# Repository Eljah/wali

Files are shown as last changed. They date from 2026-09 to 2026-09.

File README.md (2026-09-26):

# wali — робот-сборщик мусора на Java

Подготовленная для GitHub версия **UBOR-JAVA R02 / WPILib**, предназначенная для `Eljah/wali`.
Имя репозитория — `wali`; существующие Java-пакеты `com.ubor`, Maven-координаты и имена CAD-файлов сохранены.

> Это инженерный прототип, не готовый к автономной эксплуатации робот. WPILib включён в исходники R02, но сборка и выполнение WPILib в исходной среде не были подтверждены. Наличие этого пакета не означает, что репозиторий уже создан на GitHub.

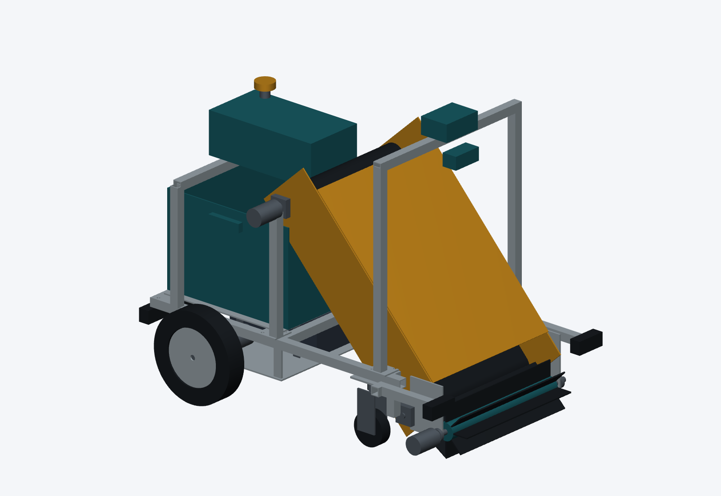
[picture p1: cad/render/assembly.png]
CAD-сборка робота


## Содержание

| Каталог | Материалы |
| --- | --- |
| `cad/` | Параметрические исходники, STEP, чертежи и спецификация механики. Нативных SolidWorks-файлов нет. |
| `electronics/` | Проект схем, перечень компонентов и соединений. |
| `software/` | Maven-проект: `robot-core`, `robot-app`, `robot-pi`, `robot-ml`, `robot-wpilib`. |
| `docs/` | Книга PDF/Markdown, глава о WPILib и инструкции. |
| `data/`, `models/` | Инструкции по данным и моделям; готовых обученных весов нет. |
| `verification/` | Сохранённые протоколы и ограничения проведённых проверок. |

## Сборка симулятора WPILib

Необходимы JDK 21, Maven 3.9+ и доступ к репозиториям зависимостей.

```bash
cd software
mvn -Pwpilib clean verify
```

Windows: `run-wpilib.cmd --desktop --nt`.
Linux: `./run-wpilib.sh --desktop --nt`.

Файл `software/dist/ubor-sim.jar` — проверенный **legacy-симулятор**, не готовая сборка WPILib.
Подробности: [README выпуска R02](README_RU.md) и [отчёт R02](verification/REPORT_R02_RU.md).
Автоматическая демонстрация использует известные сцене координаты и классы (`SIM_ORACLE_NOT_ML`), а не обученное машинное зрение.

## Документация

[Книга R02](docs/UBOR_JAVA_BOOK_R02.pdf) · [Глава WPILib](docs/25_WPILIB_R02.pdf) · [Сборка](docs/BUILD_RU.md).

## Создание репозитория

См. [PUBLISH_GITHUB_RU.md](PUBLISH_GITHUB_RU.md). Подготовлены `publish-github.ps1` и `publish-github.sh`.
По умолчанию они создают **приватный** `Eljah/wali`. Публикация требует входа в GitHub CLI на вашем компьютере.
Скрипты не заменяют существующий репозиторий и не используют force-push.
Исходные материалы R02 перенесены без изменения содержимого. Лицензия публикации автоматически не назначалась.

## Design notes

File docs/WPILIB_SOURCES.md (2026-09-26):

# Первичные источники WPILib

Версия backend зафиксирована: 2026.2.1. Просмотрено 23 сентября 2026.

- Physics Simulation: https://docs.wpilib.org/en/stable/docs/software/wpilib-tools/robot-simulation/physics-sim.html
- Drivetrain model: https://docs.wpilib.org/en/stable/docs/software/wpilib-tools/robot-simulation/drivesim-tutorial/drivetrain-model.html
- Simulated hardware: https://docs.wpilib.org/en/stable/docs/software/wpilib-tools/robot-simulation/drivesim-tutorial/simulation-instance.html
- DCMotorSim API: https://github.wpilib.org/allwpilib/docs/release/java/edu/wpi/first/wpilibj/simulation/DCMotorSim.html
- BatterySim API: https://github.wpilib.org/allwpilib/docs/release/java/edu/wpi/first/wpilibj/simulation/BatterySim.html
- EncoderSim API: https://github.wpilib.org/allwpilib/docs/release/java/edu/wpi/first/wpilibj/simulation/EncoderSim.html
- AnalogGyro API: https://github.wpilib.org/allwpilib/docs/release/java/edu/wpi/first/wpilibj/AnalogGyro.html
- Official release tag: https://github.com/wpilibsuite/allwpilib/releases/tag/v2026.2.1
- Java dependencies: https://github.com/wpilibsuite/allwpilib/blob/v2026.2.1/wpimath/build.gradle
- Native publications: https://github.com/wpilibsuite/allwpilib/blob/v2026.2.1/shared/jni/publish.gradle
- HAL native basename: https://github.com/wpilibsuite/allwpilib/blob/v2026.2.1/hal/build.gradle
- Runtime loading: https://github.com/wpilibsuite/allwpilib/blob/v2026.2.1/wpiutil/src/main/java/edu/wpi/first/util/RuntimeLoader.java

Публичная справка release может показывать версию 2026.2.2; tag для зависимости намеренно не плавающий. Наличие описания API не заменяет успешную сборку.

## Сторонние компоненты
WPILib — отдельная библиотека с лицензией BSD-3-Clause; EJML, Jackson и Quickbuf — сторонние зависимости со своими лицензиями. Бинарные зависимости в этом исходном архиве не распространяются. При создании готового дистрибутива необходимо сохранить уведомления об их лицензиях. Внутри WPILib используются штатные нативные библиотеки JNI; собственный код адаптера — Java.

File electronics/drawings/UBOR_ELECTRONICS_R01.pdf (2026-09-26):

# UBOR-JAVA R01 / Электроника

141 компонент · 100 именованных цепей · 8 дочерних схем KiCad. Вид PDF построен из канонического графа соединений, не экспортирован приложением KiCad.

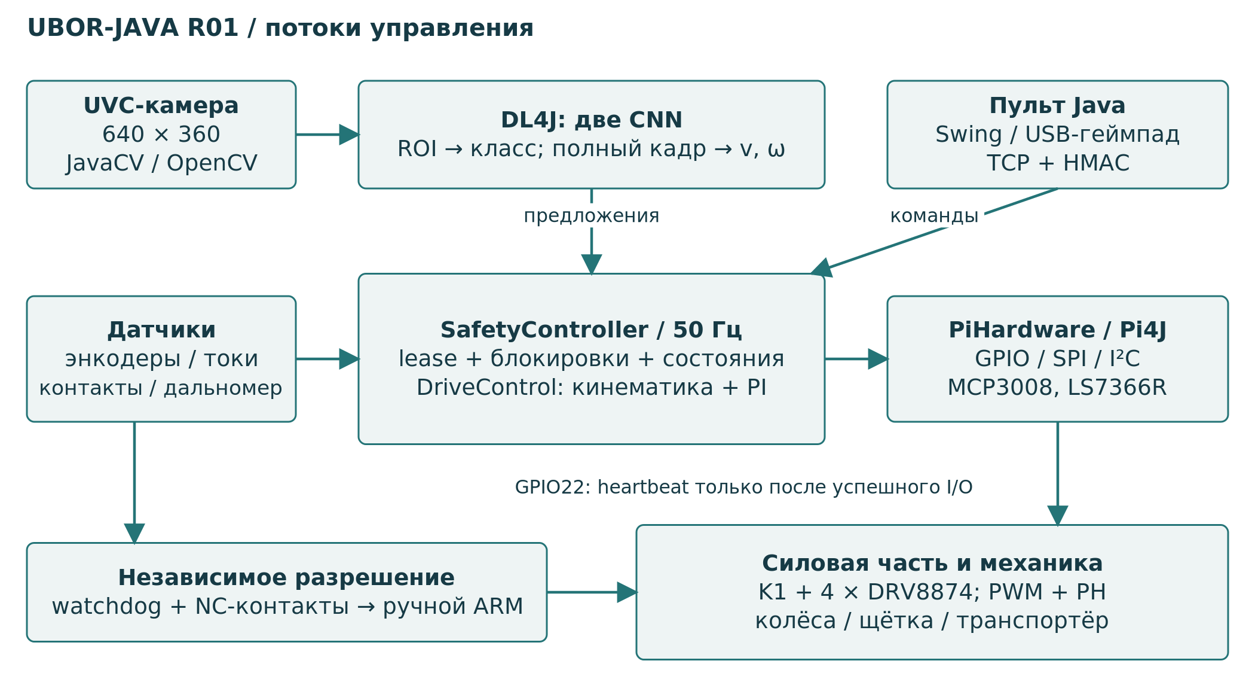
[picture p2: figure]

СТАТУС: структурная проверка выполнена. KiCad не запускался; ERC, PCB, DRC и SPICE не выполнены. Условные модульные разъёмы не являются готовыми footprint. Силовой выпуск запрещён до проверки рекуперации, тепла, предзаряда и выбранных компонентов.

Главный источник: electronics/connection_graph.json и wiring.csv. Корневой проект: electronics/kicad/UBOR_Electronics.kicad_pro. Отдельные NC-контакты состояния не соединять с цепями 24 В.

# Power / battery / precharge / motor contactor

R01 / canonical connection graph. KiCad ERC and PCB routing NOT performed.

BT1

8S LiFePO4 / BMS / 25.6V 10Ah

BAT_RAW | 1:PACK+ | 2:PACK- | GND

F1

15A DC fuse / near pack

BAT_RAW | 1:1 | 2:2 | BAT_FUSED

S0

Main DC disconnect

BAT_FUSED | 1:1 | 2:2 | BAT_SW

F2

3A logic branch

BAT_SW | 1:1 | 2:2 | BUCK_IN

PS1

Regulated 5.1V / 5A converter

BUCK_IN | 1:IN+
GND | 2:IN-
3:OUT+ | V5
4:OUT- | GND

## JUSB1

Pi5 USB-C power interface

V5 | 1:V5 | 2:GND | GND

K1

24V DC contactor + isolated feedback

BAT_SW | 1:MAIN_IN
VM_BUS | 2:MAIN_OUT
COIL_PLUS | 3:COIL+
4:COIL- | COIL_LOW
5:AUX_NO | K1_SENSE
6:AUX_COM | GND

S1B

E-STOP second NC pole

BAT_SW | 1:1 | 2:2 | COIL_PLUS

Q1

FQP30N06L / TO-220

K1_GATE | 1:G
COIL_LOW | 2:D
3:S | GND

D1

1N4007 coil diode

COIL_PLUS | 1:K | 2:A | COIL_LOW

RG1

100R gate

K1_GATE_DRIVE | 1:1 | 2:2 | K1_GATE

## RGS1

100k gate pulldown

K1_GATE | 1:1 | 2:2 | GND

## CBULK

10000uF / 50V low-ESR

VM_BUS | 1:1 | 2:2 | GND

## RBLEED

1k / 2W

VM_BUS | 1:1 | 2:2 | GND

## SPRE

Momentary PRECHARGE only

BAT_SW | 1:1 | 2:2 | PRE_R

## RPRE

22R / pulse >=5J

PRE_R | 1:1 | 2:2 | VM_BUS

## RVTOP

100k / 0.1%

BAT_SW | 1:1 | 2:2 | ADC_BAT

## RVBOT

10k / 0.1%

ADC_BAT | 1:1 | 2:2 | GND

CV

10nF

ADC_BAT | 1:1 | 2:2 | GND

# Hardware watchdog and edge-triggered manual rearm

## UWD

TPS3431 DRB

V3V3 | 1:VDD
CWD_SET | 2:CWD
V3V3 | 3:EN
GND | 4:GND
V3V3 | 5:SET1
6:WDI | HEARTBEAT
7:nWDO | WD_OK
8:ENOUT | WD_OK
9:PAD | GND

## RCWD

10k

V3V3 | 1:1 | 2:2 | CWD_SET

## RWDO

10k

V3V3 | 1:1 | 2:2 | WD_OK

## RWD_PD

100k

WD_OK | 1:1 | 2:2 | GND

S1A

E-STOP NC auxiliary

WD_OK | 1:1 | 2:2 | SAFE_1

S3A

Guard NC

SAFE_1 | 1:1 | 2:2 | SAFE_2

S4A

Bumper NC

SAFE_2 | 1:1 | 2:2 | SAFE_3

S5A

Cliff relay NC

SAFE_3 | 1:1 | 2:2 | CLEAR_N

## RCLR

100k

CLEAR_N | 1:1 | 2:2 | GND

## UFF

SN74LVC1G74 DCT/DCU

ARM_EDGE | 1:CLK
V3V3 | 2:D

3:nQ X

GND | 4:GND
5:Q | HW_ENABLE
6:nCLR | CLEAR_N
7:nPRE | V3V3
8:VCC | V3V3

## SARM

Physical ARM NO

V3V3 | 1:1 | 2:2 | ARM_BUTTON

## RARM

10k

ARM_BUTTON | 1:1 | 2:2 | ARM_RC

## RARM_PD

100k

ARM_RC | 1:1 | 2:2 | GND

## CARM

100nF

ARM_RC | 1:1 | 2:2 | GND

## USCH

SN74LVC1G17

1:NC X

ARM_RC | 2:A
GND | 3:GND
4:Y | ARM_EDGE
5:VCC | V3V3

## UAND

SN74LVC1G08

SOFT_ARM | 1:A
HW_ENABLE | 2:B
GND | 3:GND
4:Y | RUN_EN
5:VCC | V3V3

## UINV

SN74LVC1G04

1:NC X

RUN_EN | 2:A
GND | 3:GND
4:Y | PWM_OE
5:VCC | V3V3

## UGATE

SN74AHCT1G125

GND | 1:nOE
HW_ENABLE | 2:A
GND | 3:GND
4:Y | K1_GATE_DRIVE
5:VCC | V5

## RSA

10k

SOFT_ARM | 1:1 | 2:2 | GND

## RHB

10k

HEARTBEAT | 1:1 | 2:2 | GND

## RSLEEP

10k

RUN_EN | 1:1 | 2:2 | GND

## RHW

100k

HW_ENABLE | 1:1 | 2:2 | GND

## CWD

100nF at IC

V3V3 | 1:1 | 2:2 | GND

## CFF

100nF at IC

V3V3 | 1:1 | 2:2 | GND

## CSCH

100nF at IC

V3V3 | 1:1 | 2:2 | GND

## CAND

100nF at IC

V3V3 | 1:1 | 2:2 | GND

## CINV

100nF at IC

V3V3 | 1:1 | 2:2 | GND

## CGATE

100nF at IC

V5 | 1:1 | 2:2 | GND

# Raspberry Pi header and byte buses / 3.3V logic only

## JPI

Raspberry Pi5 40-pin header

V3V3 | 1:3V3
GND | 6:GND
I2C_SDA | 3:BCM2
I2C_SCL | 5:BCM3
SPI1_CS1 | 11:BCM17
SPI1_CS0 | 12:BCM18
SOFT_ARM | 13:BCM27
HEARTBEAT | 15:BCM22
ESTOP_SENSE | 16:BCM23
BUMPER_SENSE | 18:BCM24
SPI0_MOSI | 19:BCM10
SPI0_MISO | 21:BCM9
CLIFF_SENSE | 22:BCM25
23:BCM11 | SPI0_SCLK
24:BCM8 | SPI0_CS0
26:BCM7 | SPI0_CS1
29:BCM5 | GUARD_SENSE
31:BCM6 | FULL_SENSE
32:BCM12 | INTAKE_BEAM
33:BCM13 | DROP_BEAM
35:BCM19 | SPI1_MISO
36:BCM16 | DRV_FAULT_N
37:BCM26 | K1_SENSE
38:BCM20 | SPI1_MOSI
40:BCM21 | SPI1_SCLK

## UADC

MCP3008 / DIP-16

ADC_BAT | 1:CH0
CUR0 | 2:CH1
CUR1 | 3:CH2
CUR2 | 4:CH3
CUR3 | 5:CH4
RANGE_OUT | 6:CH5
GND | 7:CH6
GND | 8:CH7
9:DGND | GND
10:nCS | SPI0_CS0
11:DIN | SPI0_MOSI
12:DOUT | SPI0_MISO
13:CLK | SPI0_SCLK
14:AGND | GND
15:VREF | V3V3
16:VDD | V3V3

## UDIR

MCP23S17 / DIP-28

V3V3 | 9:VDD
GND | 10:VSS
SPI0_CS1 | 11:nCS
SPI0_SCLK | 12:SCK
SPI0_MOSI | 13:SI
SPI0_MISO | 14:SO
GND | 15:A0
16:A1 | GND
17:A2 | GND
18:nRESET | DIR_RST
21:GPA0 | DIR0
22:GPA1 | DIR1
23:GPA2 | DIR2
24:GPA3 | DIR3

## RDIR

10k

V3V3 | 1:1 | 2:2 | DIR_RST

## UPWM

PCA9685 / TSSOP28

GND | 1:A0
GND | 2:A1
GND | 3:A2
GND | 4:A3
GND | 5:A4
PWM0 | 6:LED0
PWM1 | 7:LED1
PWM2 | 8:LED2
9:LED3 | PWM3
14:VSS | GND
23:nOE | PWM_OE
24:A5 | GND
25:SCL | I2C_SCL
26:SDA | I2C_SDA
27:EXTCLK | GND
28:VDD | V3V3

## ROE

10k

V3V3 | 1:1 | 2:2 | PWM_OE

## UENC0

LS7366R / DIP14

1:fCKO X

ENC_CLK | 2:fCKi
GND | 3:VSS
SPI1_CS0 | 4:nSS
SPI1_SCLK | 5:SCK
SPI1_MISO | 6:MISO
SPI1_MOSI | 7:MOSI
8:nLFLAG | X
9:nDFLAG | X
10:nINDEX | V3V3
11:B | ENC0B
12:A | ENC0A
13:CNT_EN | V3V3
14:VDD | V3V3

## JENC0

Encoder / 3.3V quadrature

V3V3 | 1:3V3
ENC0A | 2:A
3:B | ENC0B
4:GND | GND

## UENC1

LS7366R / DIP14

1:fCKO X

ENC_CLK | 2:fCKi
GND | 3:VSS
SPI1_CS1 | 4:nSS
SPI1_SCLK | 5:SCK
SPI1_MISO | 6:MISO
SPI1_MOSI | 7:MOSI
8:nLFLAG | X
9:nDFLAG | X
10:nINDEX | V3V3
11:B | ENC1B
12:A | ENC1A
13:CNT_EN | V3V3
14:VDD | V3V3

## JENC1

Encoder / 3.3V quadrature

V3V3 | 1:3V3
ENC1A | 2:A
3:B | ENC1B
4:GND | GND

X1

1MHz CMOS oscillator / 3.3V

V3V3 | 1:OE
GND | 2:GND
3:OUT | ENC_CLK
4:VDD | V3V3

## CADC

100nF at IC

V3V3 | 1:1 | 2:2 | GND

## CDIR

100nF at IC

V3V3 | 1:1 | 2:2 | GND

## CPWM

100nF at IC

V3V3 | 1:1 | 2:2 | GND

## CENC0

100nF at IC

V3V3 | 1:1 | 2:2 | GND

## CENC1

100nF at IC

V3V3 | 1:1 | 2:2 | GND

CX

100nF at IC

V3V3 | 1:1 | 2:2 | GND

# Dry-contact safety sensing / beam inputs / range output

## SES

NC healthy; dedicated isolated auxiliary pole

ESTOP_SENSE | 1:1 | 2:2 | GND

## RSES

10k external pullup

V3V3 | 1:1 | 2:2 | ESTOP_SENSE

## SBU

NC healthy; separate contact from CLEAR chain

BUMPER_SENSE | 1:1 | 2:2 | GND

## RSBU

10k external pullup

V3V3 | 1:1 | 2:2 | BUMPER_SENSE

## SCL

NC healthy from validated cliff detector

CLIFF_SENSE | 1:1 | 2:2 | GND

## RSCL

10k external pullup

V3V3 | 1:1 | 2:2 | CLIFF_SENSE

## SGU

NC healthy

GUARD_SENSE | 1:1 | 2:2 | GND

## RSGU

10k external pullup

V3V3 | 1:1 | 2:2 | GUARD_SENSE

## SFU

NC healthy; opens when hopper full

FULL_SENSE | 1:1 | 2:2 | GND

## RSFU

10k external pullup

V3V3 | 1:1 | 2:2 | FULL_SENSE

JB0

Beam receiver / open collector

V5 | 1:V5
INTAKE_BEAM | 2:OC_3V3
3:GND | GND

RB0

10k

V3V3 | 1:1 | 2:2 | INTAKE_BEAM

JB1

Beam receiver / open collector

V5 | 1:V5
DROP_BEAM | 2:OC_3V3
3:GND | GND

RB1

10k

V3V3 | 1:1 | 2:2 | DROP_BEAM

RF

10k external pullup

V3V3 | 1:1 | 2:2 | DRV_FAULT_N

RK

10k external pullup

V3V3 | 1:1 | 2:2 | K1_SENSE

## JRANGE

Calibrated analog obstacle sensor

V5 | 1:V5
RANGE_OUT | 2:OUT_0_3V3
3:GND | GND

# DRV8874 channel 0: left

FM0

4A DC

VM_BUS | 1:1 | 2:2 | M0_VM

UM0

DRV8874 HTSSOP16-PAD

PWM0 | 1:EN
DIR0 | 2:PH
RUN_EN | 3:nSLEEP
DRV_FAULT_N | 4:nFAULT
M0_VREF | 5:VREF
M0_IP | 6:IPROPI
GND | 7:IMODE
M0_OUT1 | 8:OUT1
GND | 9:PGND
10:OUT2 | M0_OUT2
11:VM | M0_VM
12:VCP | M0_VCP
13:CPH | M0_CPH
14:CPL | M0_CPL
15:GND | GND
16:PMODE | GND
17:PAD | GND

M0

24V brushed gearmotor

M0_OUT1 | 1:+ / forward | 2:- / reverse | M0_OUT2

## CCP0

22nF / 50V

M0_CPH | 1:1 | 2:2 | M0_CPL

## CVCP0

100nF /16V

M0_VCP | 1:1 | 2:2 | M0_VM

## CVM0

100nF /50V

M0_VM | 1:1 | 2:2 | GND

CB0

470uF /50V

M0_VM | 1:1 | 2:2 | GND

## RIP0

1.5k /1%

M0_IP | 1:1 | 2:2 | GND

## RFLT0

10k

M0_IP | 1:1 | 2:2 | CUR0

## CFLT0

100nF

CUR0 | 1:1 | 2:2 | GND

## RVT0

6.19k /1%

V3V3 | 1:1 | 2:2 | M0_VREF

## RVB0

10k /1%

M0_VREF | 1:1 | 2:2 | GND

## REN0

47k

PWM0 | 1:1 | 2:2 | GND

## RPH0

47k

DIR0 | 1:1 | 2:2 | GND

CM0

10nF /50V motor suppression

M0_OUT1 | 1:1 | 2:2 | M0_OUT2

# DRV8874 channel 1: right

FM1

4A DC

VM_BUS | 1:1 | 2:2 | M1_VM

UM1

DRV8874 HTSSOP16-PAD

PWM1 | 1:EN
DIR1 | 2:PH
RUN_EN | 3:nSLEEP
DRV_FAULT_N | 4:nFAULT
M1_VREF | 5:VREF
M1_IP | 6:IPROPI
GND | 7:IMODE
M1_OUT1 | 8:OUT1
GND | 9:PGND
10:OUT2 | M1_OUT2
11:VM | M1_VM
12:VCP | M1_VCP
13:CPH | M1_CPH
14:CPL | M1_CPL
15:GND | GND
16:PMODE | GND
17:PAD | GND

M1

24V brushed gearmotor

M1_OUT1 | 1:+ / forward | 2:- / reverse | M1_OUT2

## CCP1

22nF / 50V

M1_CPH | 1:1 | 2:2 | M1_CPL

## CVCP1

100nF /16V

M1_VCP | 1:1 | 2:2 | M1_VM

## CVM1

100nF /50V

M1_VM | 1:1 | 2:2 | GND

CB1

470uF /50V

M1_VM | 1:1 | 2:2 | GND

## RIP1

1.5k /1%

M1_IP | 1:1 | 2:2 | GND

## RFLT1

10k

M1_IP | 1:1 | 2:2 | CUR1

## CFLT1

100nF

CUR1 | 1:1 | 2:2 | GND

## RVT1

6.19k /1%

V3V3 | 1:1 | 2:2 | M1_VREF

## RVB1

10k /1%

M1_VREF | 1:1 | 2:2 | GND

## REN1

47k

PWM1 | 1:1 | 2:2 | GND

## RPH1

47k

DIR1 | 1:1 | 2:2 | GND

CM1

10nF /50V motor suppression

M1_OUT1 | 1:1 | 2:2 | M1_OUT2

# DRV8874 channel 2: brush

FM2

3A DC

VM_BUS | 1:1 | 2:2 | M2_VM

UM2

DRV8874 HTSSOP16-PAD

PWM2 | 1:EN
DIR2 | 2:PH
RUN_EN | 3:nSLEEP
DRV_FAULT_N | 4:nFAULT
M2_VREF | 5:VREF
M2_IP | 6:IPROPI
GND | 7:IMODE
M2_OUT1 | 8:OUT1
GND | 9:PGND
10:OUT2 | M2_OUT2
11:VM | M2_VM
12:VCP | M2_VCP
13:CPH | M2_CPH
14:CPL | M2_CPL
15:GND | GND
16:PMODE | GND
17:PAD | GND

M2

24V brushed gearmotor

M2_OUT1 | 1:+ / forward | 2:- / reverse | M2_OUT2

## CCP2

22nF / 50V

M2_CPH | 1:1 | 2:2 | M2_CPL

## CVCP2

100nF /16V

M2_VCP | 1:1 | 2:2 | M2_VM

## CVM2

100nF /50V

M2_VM | 1:1 | 2:2 | GND

CB2

470uF /50V

M2_VM | 1:1 | 2:2 | GND

## RIP2

1.5k /1%

M2_IP | 1:1 | 2:2 | GND

## RFLT2

10k

M2_IP | 1:1 | 2:2 | CUR2

## CFLT2

100nF

CUR2 | 1:1 | 2:2 | GND

## RVT2

14.3k /1%

V3V3 | 1:1 | 2:2 | M2_VREF

## RVB2

10k /1%

M2_VREF | 1:1 | 2:2 | GND

## REN2

47k

PWM2 | 1:1 | 2:2 | GND

## RPH2

47k

DIR2 | 1:1 | 2:2 | GND

CM2

10nF /50V motor suppression

M2_OUT1 | 1:1 | 2:2 | M2_OUT2

# DRV8874 channel 3: belt

FM3

3A DC

VM_BUS | 1:1 | 2:2 | M3_VM

UM3

DRV8874 HTSSOP16-PAD

PWM3 | 1:EN
DIR3 | 2:PH
RUN_EN | 3:nSLEEP
DRV_FAULT_N | 4:nFAULT
M3_VREF | 5:VREF
M3_IP | 6:IPROPI
GND | 7:IMODE
M3_OUT1 | 8:OUT1
GND | 9:PGND
10:OUT2 | M3_OUT2
11:VM | M3_VM
12:VCP | M3_VCP
13:CPH | M3_CPH
14:CPL | M3_CPL
15:GND | GND
16:PMODE | GND
17:PAD | GND

M3

24V brushed gearmotor

M3_OUT1 | 1:+ / forward | 2:- / reverse | M3_OUT2

## CCP3

22nF / 50V

M3_CPH | 1:1 | 2:2 | M3_CPL

## CVCP3

100nF /16V

M3_VCP | 1:1 | 2:2 | M3_VM

## CVM3

100nF /50V

M3_VM | 1:1 | 2:2 | GND

CB3

470uF /50V

M3_VM | 1:1 | 2:2 | GND

## RIP3

1.5k /1%

M3_IP | 1:1 | 2:2 | GND

## RFLT3

10k

M3_IP | 1:1 | 2:2 | CUR3

## CFLT3

100nF

CUR3 | 1:1 | 2:2 | GND

## RVT3

14.3k /1%

V3V3 | 1:1 | 2:2 | M3_VREF

## RVB3

10k /1%

M3_VREF | 1:1 | 2:2 | GND

## REN3

47k

PWM3 | 1:1 | 2:2 | GND

## RPH3

47k

DIR3 | 1:1 | 2:2 | GND

CM3

10nF /50V motor suppression

M3_OUT1 | 1:1 | 2:2 | M3_OUT2

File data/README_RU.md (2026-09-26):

# Данные обучения

Реального датасета в R01 нет. PNG, созданные симулятором, — синтетические диагностические кадры, а не обучающая выборка с заявленной точностью.

На этапе объездки Java DatasetRecorder записывает кадры и manifest в явно заданный выходной каталог. Метки предметов задаёт человек. В manifest сохраняются разрешённые контроллером, а не просто запрошенные, линейная и угловая скорости. Примеры файлов разбиения по целым сессиям и bounding boxes находятся в `software/config`.

Сначала собрать независимые поездки, затем разнести целые session_id между train/validation/test, проверить метки и подготовить отдельные ROI для классификатора. Модель движения обучается на полном кадре. Команды подготовки, обучения и проверки приведены в главах 16–19 книги. Соседние кадры одной поездки нельзя случайно перемешивать между обучением и тестом.

Обученных моделей в архиве нет. Их контрольные суммы, статус допуска и согласованные параметры камеры должны оформляться после целевых испытаний.

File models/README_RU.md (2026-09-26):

# Модели намеренно не подменены заглушками

В комплекте нет обученных весов, полевых фотографий и придуманной точности.
Исходники двух CNN, обучения и проверки — `software/robot-ml`.

Аппаратный режим ожидает `classifier.zip` и `policy.zip` с соответствующими
`*.zip.properties`, создаваемыми `com.ubor.ml.Trainer`.
Преобразование RGB64 NCHW, порядок классов, SHA-256, `kind` и
`approved.for.hardware` проверяются загрузчиком. Trainer записывает
`approved.for.hardware=false`; перевод в true — ручной выпуск после независимой
проверки метрик, локализации, времени получения кадра и работы на стенде.

`--desktop` и `--demo` не используют нейросеть. Их распознавание — oracle из
состояния мира. Для первичного датасета есть `--hardware-teleop` (только камера).
Никогда не обучайте реальную модель на oracle-кадрах с обещанием полевой точности.

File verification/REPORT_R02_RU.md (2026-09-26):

# Проверка UBOR R02 / WPILib

Дата выпуска: 23 сентября 2026. Среда: Linux x86-64, OpenJDK 21.0.11.

| Объект | Результат | Доказательство |
|---|---|---|
| Компиляция robot-core + robot-app | PASS | offline-build.log; software/dist/ubor-sim.jar |
| Прежние проверки ядра и интеграции | PASS, 50 assertions | r02-core/ |
| Граница сменной физики | PASS, 20 assertions, тестовая модель | r02-boundary/ |
| Загрузка/валидация параметров | PASS, 9 assertions, без WPILib | r02-parameters/ |
| Реальный TCP/HMAC loopback | PASS, 40 обменов, останов после отключения | network-legacy-r02.txt |
| Синтаксис Java | PASS, 37 файлов, только parse | java-parse.txt |
| Компиляция модуля robot-wpilib | NOT RUN | wpilib-build-attempt.txt; Maven отсутствует |
| Загрузка WPILib | BLOCKED | dependency-download-attempt.txt; DNS/соединение недоступны |
| Native HAL / WPILib runtime | NOT RUN | wpilib-launch-attempt.txt |
| 25 проверок WpiVerification | Подготовлены; НЕ выполнены | software/robot-wpilib/src/main/java/com/ubor/wpilib/WpiVerification.java |
| Windows / macOS | НЕ выполнено | предусмотрены скрипт и профили, без подтверждённого запуска |
| Raspberry Pi / Pi4J / DL4J / аппаратная часть | НЕ выполнено в R02 | исходные ограничения R01 сохраняются |

**Нельзя считать 50+20+9 проверок доказательством работающей WPILib.** В тестах границы используется класс Probe с именем `TEST_DOUBLE_NOT_WPILIB`. Он не подменяет классы edu.wpi.first.* и не входит в WPILib backend.

Выполненная проверка синтаксиса использует JavacTask.parse(): импорты и сигнатуры внешних библиотек ею НЕ проверяются. Никакие суррогатные классы WPILib для имитации успешной компиляции не создавались.

Для полной проверки: из `software` выполнить `mvn -Pwpilib clean verify`. Отчёт нового запуска должен появиться в `robot-wpilib/target/wpilib-report/result.json`. Только статус PASS этого нового запуска подтверждает выполнение подготовленных WPILib-сценариев. В начале проверки отчёт заменяется на RUNNING_NOT_YET_PASSED, чтобы не оставлять ложный старый PASS при аварийном завершении.

Механика, электронные схемы и ML не стали автоматически верифицированными после добавления симулятора. Модель движения требует калибровки по физическому роботу; моменты инерции и параметры двигателей пока задают гипотезу.

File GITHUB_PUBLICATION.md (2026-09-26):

# GitHub publication

The original wali/UBOR-JAVA R02 package was imported as ordinary files. All 316 source files were checked byte-for-byte against the exact original archive, including the 307 entries of its original manifest.

See verification/github-import.json and verification/github-source-manifest.json. The pre-publication reports remain unchanged historical records. This import does not establish that WPILib, DL4J or physical hardware tests passed.

The pre-existing lowercase readme.md was preserved as docs/ORIGINAL_REPOSITORY_README.md to avoid a case-insensitive filesystem collision. No force-push was used.

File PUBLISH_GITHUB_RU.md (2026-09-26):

# Публикация `Eljah/wali`

## Текущее состояние

Этот пакет подготовлен локально. Репозиторий **не создан**, файлы в GitHub **не отправлены**.
GitHub-подключение в чате подтвердило аккаунт Eljah, но не предоставило операций создания/записи;
в рабочей среде не было авторизованного CLI. Запрос `Eljah/wali` вернул 404:
это не доказывает отсутствие репозитория, поскольку он мог быть недоступен подключению.

## Перед запуском

Установите Git и GitHub CLI (`gh`). На Windows доступны команды:

```powershell
winget install --id Git.Git --exact
winget install --id GitHub.cli --exact
```

Откройте новый терминал после установки. Распакуйте ZIP и перейдите в каталог `wali`.
Не добавляйте в него реальные ключи, записи личных данных и пароли перед публикацией.

Выполните вход через браузер именно в аккаунт **Eljah**:

```text
gh auth login --hostname github.com --git-protocol https --web
```

Разрешите настройку аутентификации Git, когда CLI спросит об этом.
Токены и пароль в чат передавать не нужно.

## Windows / PowerShell

```powershell
powershell -NoProfile -ExecutionPolicy Bypass -File .\publish-github.ps1
```

`-ExecutionPolicy Bypass` действует только для этого запуска PowerShell и не меняет постоянную политику.
Сначала ознакомьтесь с текстом скрипта. По умолчанию репозиторий будет **private**.
Для осознанной публичной публикации добавьте `-Visibility public`.

## Linux / macOS / Git Bash

```bash
bash publish-github.sh
```

Для публичной публикации: `bash publish-github.sh public`.

## Что делает скрипт

Проверяет наличие файлов и программ, получает аккаунт через `gh api user` и требует `Eljah`.
При наличии локального `.git` останавливается, не меняя существующий репозиторий.
Создаёт локальную ветку `main`, задаёт имя и noreply-email автора **только в локальной Git-конфигурации**,
добавляет материалы и создаёт первый коммит. Затем вызывает:

```text
gh repo create Eljah/wali --private --source=. --remote=origin --push
```

В конце сравнивает SHA локального коммита и удалённой `main`.
Скрипт не удаляет репозитории, не меняет видимость существующего репозитория и не делает force-push.
Приватность существующего репозитория не изменяется.

## При сбое

При ошибке скрипт завершается. Локальная `.git` может уже существовать; удалённый репозиторий мог быть
создан до ошибки отправки. **Не удаляйте его и не используйте `--force`.** Проверьте:

```text
git status
git remote -v
gh repo view Eljah/wali --json nameWithOwner,url,isPrivate
```

Если подтверждено, что это созданный этим запуском пустой репозиторий, а `origin` указывает именно на него,
после устранения проблемы авторизации достаточно `git push -u origin main`.
Если репозиторий существовал раньше, сопоставьте его содержимое с проектом отдельно; скрипт его не заменяет.

## Проверка пакета

308 исходных файлов R02 сохранены байт-в-байт; добавлены только файлы оформления и публикации.
Проверки упаковки не заменяют запуск WPILib или испытания электроники.
Публикация через реальный GitHub API здесь не выполнялась.

## Официальная документация CLI

- https://cli.github.com/manual/gh_repo_create
- https://cli.github.com/manual/gh_auth_login
- https://cli.github.com/manual/gh_auth_setup-git

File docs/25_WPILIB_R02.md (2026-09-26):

# Глава 25. Интеграция WPILib — UBOR R02

Дата: 23 сентября 2026. Исходный код; WPILib-сборка не верифицирована.

## 25. WPILib в проекте UBOR

R02 заменяет способ расчёта движения, а не архитектуру управления. Пульт, сетевой протокол, SafetyController и DriveControl остаются теми же. Между сценой Simulator и физической моделью появился интерфейс SimDynamics; его реализация WpilibDynamics вызывает классы WPILib 2026.2.1.

**Статус: исходный код интеграции подготовлен. Сборка и выполнение WPILib здесь НЕ проверены: Maven отсутствует, загрузка бинарных зависимостей недоступна. Работоспособность готового WPILib-дистрибутива этим выпуском не заявляется.**

### Как проходит один цикл

```text
TCP/HMAC -> RobotService
  -> SafetyController -> DriveControl -> Actuation
  -> Simulator -> WpilibDynamics
  -> физическое состояние и HAL-датчики
  -> Sensors -> следующий цикл контроллера
```

Simulator больше не вычисляет координаты в WPILib-пути. Он получает готовую позу, скорости колёс, путь, скорости механизмов, токи и напряжение. Старый способ расчёта оставлен для регрессионной проверки и всегда называется LEGACY_FIRST_ORDER.

### Что осталось от R01

Механика STEP/CAD и электрические схемы не менялись. Аппаратный адаптер Pi4J и код DL4J сохранены. Включение профиля wpilib не собирает профиль full и не требует загружать библиотеки обучения. В собственной программе нет кода C/C++; штатные нативные библиотеки WPILib используются через JNI.

Вариант запуска называется явно. run-simulator теперь вызывает WPILib; run-legacy-simulator вызывает старый JAR. Если WPILib не собран или не загружается JNI, запуск завершается ошибкой. Автоматического перехода к старой физике нет.

## 25.1. Приводы и батарея

Для дифференциального шасси применяется DifferentialDrivetrainSim. Щётка и приводной ролик транспортёра представлены двумя DCMotorSim. Напряжение на моторе получается из PWM-доли и напряжения шины, а не из прямого назначения скорости колесу.

| Параметр | Значение / происхождение |
|---|---|
| Масса; колея; радиус | 30 кг; 0,5 м; 0,1 м — исходные условия R01 |
| Момент инерции по курсу | 2,4 кг·м² — оценка, не измерение CAD-массовой модели |
| Редукции: колёса / щётка / лента | 112,5 / 25 / 38,8 — допущения |
| Моторы | Собственные наборы DCMotor на 24 В; не NEO/CIM из примера FRC |
| Батарея | 25,6 В; 0,09 Ом; электроника 1 А — допущения |
| Радиус ролика | 0,025 м; скорость ленты = угловая скорость × радиус |

Конфигурация находится в config/wpilib-sim.properties. Параметры двигателя относятся к валу ДО редуктора; смешение паспортных характеристик редукторного выхода с коэффициентом редукции удвоит преобразование. Ширина колеи и радиус дополнительно сверяются с константами DriveControl.

### Просадка питания

```text
I_source = I_logic + sum(max(0, duty * I_winding))
V_loaded = BatterySim.calculateLoadedBatteryVoltage(
    V_open, R_internal, I_source)
```

Ток, который видит датчик мотора, — модуль тока обмотки. Для батареи используется оценка среднего входного тока PWM. Установлено напряжение моделируемой шины 25,6 В: стандартные 12 В из FRC-примеров не подставляются автоматически. Химия, заряд батареи, температура, токовые ограничения драйвера и рекуперативное перенапряжение здесь не моделируются.

## 25.2. HAL, время и отключение

WpiSensors записывает результат модели в EncoderSim, AnalogInputSim, DIOSim и RoboRioSim, затем считывает его через обычные объекты WPILib. Именно эти показания энкодеров и токов поступают в общий контроллер. Это проверяет программную обратную связь, но не исполняет SPI-протокол LS7366R/MCP3008 и не эмулирует Raspberry Pi.

| Виртуальные каналы | Назначение |
|---|---|
| DIO 0–3 | Два энкодера; метры и импульсы согласованы с DriveControl |
| AI 0 | AnalogGyroSim: диагностический угол, не реальный IMU в схеме |
| AI 1 / AI 2–5 | Дальность 1 В/м / токи 0,5 В/А; насыщение 0–5 В |
| DIO 4–12 | NC-защиты, заполнение, разрешение, ошибка драйвера, два луча |
| RoboRioSim VIn | Симулируемая шина питания, а не питание физического roboRIO |

Ось курса в физике положительна против часовой стрелки; AnalogGyro.getAngle использует противоположный знак. Адаптер учитывает это. Гироскоп используется для диагностики и отдельной проверки, а существующий контур DriveControl регулирует скорости по энкодерам.

### Частоты и защёлки

Управляющий цикл работает с периодом 20 мс. Физика разбивается на подшаги до 5 мс, независимо от интерфейса пульта. Истечение 200-мс watchdog размыкает виртуальное разрешение; очистка аварийного признака не включает питание. Требуется новое действие Physical ARM. Пауза модели свыше 5 с отклоняется явно, а не маскируется потерей времени.

**Обесточить моторы — не то же самое, что мгновенно остановить колёса. Нулевое входное напряжение в DC-модели соответствует электрическому торможению. Для разомкнутой цепи в R02 введена отдельная приближённая модель выбега с пассивным сопротивлением. Её коэффициент НЕ откалиброван; безопасный тормозной путь не подтверждён.**

## 25.3. Сборка и работа с пультом

Требования: JDK 21, Maven 3.9+ и доступ к Maven Central/FRCMaven. В pom зафиксирована WPILib 2026.2.1. Схема сборки использует Java JAR и платформенные архивы *-cpp с JNI/shared-библиотеками. Maven распаковывает библиотеки в target/native; скрипты задают java.library.path и путь поиска зависимых DLL/SO.

```text
cd software
mvn -Pwpilib clean verify
```

verify запускает реальные проверки WPILib отдельной JVM. Файлы Java из robot-pi/robot-ml не включаются, пока не выбран профиль full. Для Windows предусмотрен windowsx86-64, для Linux — linuxx86-64, для macOS — osxuniversal; эти платформенные сборки в данной среде не проверены. Linux ARM не является целевой конфигурацией этого настольного запуска.

### Windows

```text
run-wpilib.cmd --about
run-wpilib.cmd --desktop --nt
run-wpilib.cmd --demo ..\verification\my-demo 90
```

### Linux

```text
./run-wpilib.sh --about
./run-wpilib.sh --desktop --nt
./run-wpilib.sh --demo ../verification/my-demo 90
```

В пульте сначала нажать Physical ARM (SIM), затем Arm / Disarm и удерживать SPACE. Движение — стрелки/WASD; C — ручной подбор с человеческой меткой. Для записи добавить --record каталог. Это синтетические кадры симулятора, а не фотографии полигона.

Опция --nt публикует Field2d и телеметрию на 127.0.0.1:5810 для Glass. Команды управления по NetworkTables не принимаются. В headless-режиме --server доступны консольные команды arm, estop, restore, jam; сетевой сервер также по умолчанию слушает только loopback.

## 25.4. Что проверено, а что нет

| Проверка в среде подготовки | Результат |
|---|---|
| Ядро + старый симулятор | 50 проверок — PASS |
| Интерфейс сменной физики | 20 проверок с TEST_DOUBLE_NOT_WPILIB — PASS |
| Конфигурация физических параметров | 9 проверок без WPILib — PASS |
| TCP/HMAC на старой модели | 40 обменов и останов после разрыва — PASS |
| Синтаксис Java | 37 файлов, только parse — PASS |
| Компиляция / исполнение WPILib | НЕ ВЫПОЛНЕНО |
| WpiVerification | 25 проверок подготовлены, НЕ выполнены |

Двадцать проверок интерфейса подтверждают, что сцена берёт координаты, скорости и токи из подключённого backend; не пересчитывает их повторно; передаёт останов и заклинивание; закрывает ресурсы ровно один раз. Тестовая модель намеренно имеет отличное от WPILib имя и не подменяет классы edu.wpi.first.*.

Реальная suite WpiVerification должна проверить движение прямо и назад, поворот, знак гироскопа, энкодеры HAL, 25-вольтовую шину, выбег после отключения, вращение щётки/ролика, заклинивание и токи, watchdog, аварийные защёлки, полный сбор трёх предметов и TCP-отключение.

### Где смотреть результат

```text
robot-wpilib/target/wpilib-report/result.json
robot-wpilib/target/wpilib-report/wpilib-origin.txt
robot-wpilib/target/wpilib-report/oracle-demo/
verification/REPORT_R02_RU.md
```

В начале запуска статус заменяется на RUNNING_NOT_YET_PASSED. При исключении записывается FAIL; только завершение всей suite формирует PASS. Источник JAR фиксируется отдельно. Протоколы r01_archive и r02-core не являются свидетельством выполнения WPILib. Проверка parse не проверяет типы и внешние сигнатуры.

## 25.5. Границы модели и следующий стенд

Зрение в демонстрации называется SIM_ORACLE_NOT_ML: класс и координаты предмета известны сцене. WPILib не превращает такую демонстрацию в проверку DL4J. Качество детекции, обучение рулению, ложные срабатывания на тени и неизвестных предметах требуют отдельного набора данных и испытаний.

Сбор мусора остаётся геометрическим автоматом: предмет входит в зону подборщика, переходит на ленту и затем в бункер. Скорость продвижения теперь зависит от скорости ролика DCMotorSim. Если механизмы стоят, одной положительной команды недостаточно. Контакт не моделирует пластичность бутылки, изгиб бумаги, наматывание пакета и силы щетины.

Из сцены убрана ошибка R01: проверка collectible() в самой механике запрещала подбор опасного предмета даже при неверном управлении. Теперь материальный объект не имеет такой защиты, и запрет должен обеспечивать контроллер. Отдельная проверка интерфейса подтверждает возможность физического захвата объекта HAZARD при прямой неправильной команде.

### Калибровка после появления прототипа

Сначала определить параметры купленных двигателей и редукторов, действительные импульсы энкодеров, массы и моменты инерции. На вывешенных колёсах снять скорость и ток как функции PWM/напряжения; на полу измерить разгон, поворот и свободный выбег с разной загрузкой. Сравнивать временные ряды энкодеров и токов, а не только конечную точку маршрута.

Для этапа сборщика отдельно измерить разгон щётки и ленты, ток при контакте с эталонными предметами и последствия наматывания. Сначала завершить независимую аварийную цепь и физические испытания защиты. Программная симуляция не обосновывает безопасное использование рядом с людьми.

### Первичные источники

WPILib: Physics Simulation, Drivetrain Simulation Tutorial, Device Simulation, API DCMotorSim/BatterySim. Исходные сигнатуры и состав зависимостей сверены с репозиторием wpilibsuite/allwpilib, тег v2026.2.1. Полные адреса приведены в docs/WPILIB_SOURCES.md. Новая глава дополняет R01 и не снимает его инженерных ограничений.

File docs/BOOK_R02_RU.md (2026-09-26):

# UBOR R02: исходная книга R01 + дополнение WPILib

Статус WPILib: код интеграции; сборка и запуск не проверены.

# Предисловие. От идеи к проверяемой машине

Робот, который узнаёт бутылку на фотографии, и робот, который доставляет эту бутылку в бункер, — разные устройства. Между ними лежат геометрия входного окна, сцепление колёс, ток двигателя, задержка камеры, состояние ленты и решение оператора. Эта книга описывает один связанный проект, а не коллекцию независимых примеров. Его имя — UBOR-JAVA R01.

Проект создан для проверки идеи на закрытом полигоне. Он включает настоящую твердотельную CAD-модель, схему соединений электроники, исходный Java-проект, запускаемый симулятор и код обучения. При этом физический робот ещё не построен, аппаратные модули не прошли проверку на Raspberry Pi, а обученных весов в комплекте нет. Эти границы важны: хороший инженерный прототип начинается с возможности точно сказать, что уже проверено, а что пока является гипотезой.

Слово «прошивка» здесь используется в бытовом смысле бортового программного обеспечения. Самостоятельной платы с STM32 и программой на C в R01 нет. На Raspberry Pi работает Java-процесс, который читает датчики, формирует команды приводам, принимает пульт и вызывает нейросети. Таймер PWM, аппаратные счётчики энкодеров и сторожевой таймер выполняются покупными микросхемами без нашей микропрограммы. Linux, JVM и численные библиотеки, разумеется, не переписываются на Java.

В книге последовательно разделены расчёт, программа и эксперимент. Например, расчётная тяга 3,15 Н·м на колесо не является измеренным моментом выбранного мотора; успешный TCP-тест не означает испытанную радиосвязь на улице; три собранных предмета в симуляторе не доказывают качество машинного зрения. Такое разделение позволяет дорабатывать проект без потери доверия к его результатам.

Основной маршрут чтения: сначала область применения и архитектура, затем механика и электрическая часть, после этого Java, обучение и стендовый выпуск. Тем, кто хочет немедленно увидеть работающую программу, достаточно открыть главу 12. Книга сопровождает конкретные файлы R01: названия классов и команд соответствуют исходникам в архиве.

> Статус издания: инженерный proof of concept, 23 сентября 2026 года. Не рабочая документация для немедленного изготовления, не руководство по эксплуатации сертифицированного изделия.

Рисунок 1. Общий вид, программно полученный из той же CAD-сборки, которая передаётся в STEP.

# 01. Какую задачу мы действительно решаем

Первое ограничение — не вычислительная мощность, а определение мусора. Для R01 допускаются сухая бумага, пустая пластиковая бутылка и пустая металлическая банка. Предмет должен находиться на открытой ровной поверхности, быть доступен переднему подборщику и не содержать опасного вещества. Осколки, шприцы, аккумуляторы, провода, жидкость, горячие предметы и неизвестные упаковки не входят в испытательный набор. Даже пустую банку предварительно осматривает человек.

Классы программы называются NONE, PAPER, PLASTIC_BOTTLE, METAL_CAN, HAZARD и UNKNOWN. Первые три предметных класса допускаются к подбору. NONE обозначает отсутствие цели. UNKNOWN означает недостаточно определённый объект. HAZARD нужен для отказа, но распознавание этого класса не заменяет охрану рабочей зоны. На первых испытаниях вместо опасного предмета используется безопасный макет с соответствующей разметкой.

Робот не сортирует собранный материал по нескольким контейнерам. Здесь один бункер. Классификация отвечает на вопрос «можно ли принять этот предмет», а не управляет распределением фракций. Для настоящей раздельной сортировки потребуются заслонка, несколько накопителей, контроль положения заслонки и новая пространственная модель траектории падения. В R01 этих деталей и этой логики нет.

Рабочая зона — ограждённый полигон без прохожих, лестниц, транспорта, детей и животных. Оператор находится рядом и видит машину непосредственно. Предполагается ровное сухое покрытие; расчёт уклона 5° служит ориентиром для тяги, а не разрешением работать на любом склоне. Объезд препятствий в неизвестной среде, построение карты, движение между кварталами и автоматическая зарядная станция не реализованы.

| Параметр | Принято в R01 | Что нужно подтвердить |
|---|---|---|
| Полная масса | 30 кг | Взвешивание собранной машины |
| Полезная нагрузка | Не более 4 кг | Прочность, торможение, устойчивость |
| Ручная скорость | До 0,30 м/с | Фактическая скорость под нагрузкой |
| Автоматическая скорость | До 0,20 м/с | Задержка зрения и остановка |
| Скорость при подборе | До 0,08 м/с | Геометрия захвата, проскальзывание |
| Покрытие | Сухое, ровное, закрытая площадка | Испытание колёс и губы подборщика |
| Сортировка | Только допуск/отказ, один бункер | Дополнительные фракции не поддержаны |

Критерий успеха первого этапа прост: оператор безопасно подводит машину к известному предмету, предмет входит на ленту, задний датчик подтверждает его выход, а после потери команды робот прекращает движение. Только после этого имеет смысл поручать нейросети выбор направления и момента начала подбора. Иначе обучение будет маскировать механическую проблему, которую никакой датасет не исправит.

# 02. Архитектура: четыре независимых вопроса

В любой момент система должна ответить на четыре вопроса: что перед машиной, что оператор разрешил, в каком состоянии механика и можно ли вообще включать приводы. Эти ответы разделены между восприятием, командным каналом, датчиками и контуром разрешения. Ни один ответ сам по себе не является приказом вращать мотор.

Верхний уровень — камера и две DL4J-модели. Классификатор оценивает фрагменты изображения. Модель движения по полному кадру предлагает линейную и угловую скорость. Предложения поступают в SafetyController, который проверяет свежесть, допустимость объекта, препятствие, пульт и состояние машины. Только после этого DriveControl превращает разрешённую скорость в сигналы левого и правого двигателя.

Нижний программный уровень — PiHardware. Он реализует чтение входов и обмен байтами с периферией через Pi4J. SPI нужен АЦП, расширителю направлений и двум счётчикам энкодеров. I²C нужен многоканальному генератору PWM. Непосредственные GPIO используются для блокировок, heartbeat, программного разрешения и оптических датчиков.

Независимый аппаратный уровень — физический аварийный останов, последовательная цепь нормально замкнутых контактов, TPS3431, триггер ручного повторного пуска и контактор K1. Он не спрашивает нейросеть, безопасно ли продолжать движение. Потеря heartbeat сбрасывает аппаратное разрешение. Возобновление Java-процесса не должно автоматически вернуть питание приводам.

Рисунок 2. Структура R01: нейросеть предлагает, контроллер ограничивает, аппаратный контур отдельно разрешает питание.

Модули Maven повторяют эту границу. `robot-core` не зависит ни от Pi4J, ни от DL4J; его можно проверять без Интернета. `robot-app` содержит симулятор, пульт, транспорт и исполняемый вход. `robot-pi` связывает байтовые интерфейсы с настоящими шинами. `robot-ml` содержит камеру, обработку изображений, сети и обучение. Такая структура не делает аппаратные ошибки невозможными, но позволяет определить, на какой границе возникло расхождение.

Все собственные алгоритмы управления, обучения и пульта написаны на Java. Python-файлы в архиве — инструменты генерации CAD, электрических исходников и документов. Они не работают на борту вместо заявленного Java-кода. В свою очередь, DL4J использует нативный вычислительный backend, а доступ к аппаратуре и видео зависит от Linux и нативных библиотек. Это Java-приложение, а не обещание чистой Java до последнего машинного такта. [1–3]

# 03. Механическая компоновка и единый источник геометрии

Механическая модель создана в CadQuery/OpenCascade. Исходник `cad/src/build_robot.py` формирует именованные тела и экспортирует сборку, отдельные детали и проекции. Из этой же геометрии получены изображения книги. Здесь нет независимой красивой картинки, по которой затем приблизительно восстановлен чертёж: исходная геометрия одна.

Система координат: X направлен вперёд, Y — поперёк машины, Z — вверх. Плоскость пола имеет Z = 0. Ведущая ось расположена около X = −190 мм, передние опоры поддерживают зону подбора. Колея ведущих колёс — 500 мм, диаметр — 200 мм. Рама в плане занимает 660 × 430 мм и выполнена из квадратного профиля 20 × 20 × 2 мм.

Габарит STEP при обратном чтении: 809,5 × 545,0 × 665,0 мм. При вычислении исходной сборки с допусками ядра получены очень близкие значения 809,5 × 545,14 × 665,07 мм. Для компоновки следует пользоваться округлённым размером около 810 × 545 × 665 мм, а при проверке конкретного зазора измерять соответствующие поверхности, не вычитать округлённые габариты.

В сборке 121 именованное твердотельное тело. Число тел не равно числу закупаемых артикулов: отдельные тела могут представлять части условного покупного узла. Упрощённый мотор, подшипниковая опора и корпус камеры показывают занимаемый объём и предполагаемый интерфейс. Они не являются каталоговыми моделями выбранного производителя. До закупки и выпуска рабочих чертежей эти интерфейсы нужно заменить фактическими.

Бункер расположен позади верхнего ролика. Батарея — ниже, на отдельной опоре; электроника — выше бункера на собственной несущей конструкции. Бункер извлекается назад, а не сквозь расположенный сверху блок электроники. Сервисный STEP показывает его смещение на 420 мм назад. Для обслуживания за машиной необходима свободная зона; наличие сервисной конфигурации не доказывает, что провод или забытый болт не перекроет эту зону после сборки.

Рисунок 3. Вид с убранными закрывающими элементами: несущая структура и расположение узлов.

Файлы STEP доступны большинству инженерных CAD, поддерживающих этот формат. Нативные SLDPRT/SLDASM не созданы, проверка открытия именно в SolidWorks не выполнялась. После импорта тела обычно не получают исходную историю параметрических операций CadQuery. Изменять базовую конструкцию надёжнее в исходнике и заново экспортировать STEP; локальная доработка в выбранной CAD допустима, но создаёт вторую ветвь геометрии, которую нужно версионировать.

Проверка валидности тел отвечает на вопрос о корректности топологии. Она не проверяет автоматически прочность, технологичность, крепление всех покупных изделий или отсутствие всех столкновений при движении. У гибкой щётки есть намеренный контакт с губой, а ременная передача идеализирована. Такие места требуют физической модели или стенда, а не простого запрета на пересечение твёрдых тел.

# 04. Тяга, скорость, масса и запас энергии

Расчёт тяги начинается с полной массы, а не с массы алюминиевой рамы. В R01 приняты 30 кг: сюда должны войти батарея, провода, крепёж, приводы, электроника и содержимое бункера. Оценочная масса смоделированных частей с некоторыми заменами на массы покупных узлов составляет 24,31 кг. При полезной нагрузке 4 кг остаётся около 1,69 кг до расчётного предела. Это небольшой резерв; его нельзя тратить повторно в нескольких подсистемах.

Для предварительного расчёта приняты коэффициент сопротивления качению 0,03, уклон 5° и ускорение 0,25 м/с². Это проектные предположения, не измерения. Сила на движителях складывается из сопротивления качению, составляющей тяжести и инерции:

```text
F = m·g·(sin α + c_r·cos α) + m·a
m = 30 кг; g = 9,81 м/с²; α = 5°; c_r = 0,03
F ≈ 41,95 Н
T_одного_колеса = (F / 2) · r · 1,5
r = 0,10 м; T ≈ 3,15 Н·м
```

Множитель 1,5 — выбранный предварительный запас, а не универсальное нормативное требование. Для дальнейшего подбора задано не менее 4 Н·м длительного момента на выходе каждого редуктора при скорости около 30 об/мин под нагрузкой. Нельзя заменить длительный момент моментом заклинивания или принять рекламные «6 А» драйвера за допустимый бесконечный ток системы. Проверяется вся цепь: мотор, редуктор, муфта, вал, подшипники, колесо и охлаждение драйвера.

При скорости 0,30 м/с колесо радиусом 0,10 м вращается с частотой примерно 28,65 об/мин. Расчёт говорит, что редуктор со скоростью 300 об/мин потребует другого управления и существенно большего запаса по минимальной устойчивой скорости. Он не становится эквивалентным варианту 30 об/мин просто после ограничения PWM до десяти процентов: меняются момент, нагрев и старт под нагрузкой.

Аккумулятор в компоновке — готовая защищённая сборка 8S LiFePO4, номинально 25,6 В и 10 А·ч. Номинальная энергия равна 256 Вт·ч. При условных 80 Вт средней нагрузки, 80% используемой энергии и 90% эффективности цепи получается 2,304 часа. Это сценарная оценка. На реальной машине средний ток щётки, ленты, камеры и вычислителя нужно записать за полный цикл и повторить расчёт по измеренному профилю.

```text
E_nom = 25,6 · 10 = 256 Вт·ч
t_оценка = 256 · 0,8 · 0,9 / 80 ≈ 2,30 ч
```

Для одной балки профиля 20 × 20 × 2 мм момент инерции сечения равен 7872 мм⁴. В принятой простой балочной схеме исходник получает напряжение около 30,84 МПа и прогиб 1,62 мм. Этот расчёт полезен как сигнал порядка величин, но не заменяет проверку соединений, вырыва отверстий, сварного шва, усталости и концентраций напряжений. Если рама изготовлена из материала с другой маркой и термообработкой, нельзя переносить допустимые напряжения без проверки.

# 05. Щётка, лента и геометрия приёма

Передний подборщик выбран вместо манипулятора, чтобы уменьшить число управляемых степеней свободы. Машина сама подводит приёмное окно к предмету. Гибкая щётка помогает завести предмет на губу и нижний участок ленты. Лента переносит предмет выше борта бункера и сбрасывает внутрь. Эта схема проще руки с захватом, но хуже выбирает один предмет из тесной группы и чувствительна к форме покрытия.

Ширина рабочего канала — 320 мм. Ось щётки расположена около X = 383 мм, Z = 62 мм, наружный радиус гибких лопастей — 57 мм. Губа подборщика подходит к полу примерно на 4 мм. Малый зазор облегчает подбор бумаги, но увеличивает риск зацепа за шов плитки. Поэтому первоначальный полигон должен быть гладким; имитация дорожного бордюра не входит в начальные испытания.

Оси роликов ленты: нижняя (300; 0; 85) мм, верхняя (−30; 0; 445) мм. Межосевое расстояние составляет 488,36 мм, угол наклона — 47,49°. Для расчётного радиуса средней линии 26,5 мм получаем длину замкнутой средней линии около 1143,23 мм:

```text
C = sqrt((300 + 30)² + (445 − 85)²) = 488,36 мм
L ≈ 2·C + 2·π·26,5 = 1143,23 мм
```

Это не заказная длина промышленной ленты. Производитель может нормировать внутреннюю длину, длину по корду, допуск натяжения или шаг зацепления. Реальный материал растягивается, шов занимает место, а поверхность ролика может иметь покрытие. Перед заказом нужно выбрать тип ленты, натяжитель и способ крепления поперечных планок, затем пересчитать длину по правилам изготовителя.

В CAD поперечные планки и поверхность ленты идеализированы. При наклоне около 47,5° одной силы трения может не хватить: предмет будет скатываться. Поэтому нужны экспериментальные прогоны с бумагой, бутылкой и банкой разных размеров. Результат фиксируется отдельно для входа на ленту, удержания между планками и сброса в бункер. Один показатель «подобрано» скрывает разные причины отказа.

Входной лучевой датчик подтверждает пересечение приёмной зоны, выходной — выгрузку. По одному наличию изображения нельзя решить, что предмет уже лежит в бункере. В R01 после подтверждённого входа машина останавливает шасси и довозит уже принятый предмет лентой. По истечении времени переноса без выходного подтверждения процесс завершается отказом, а не бесконечным вращением.

Руки и одежда не должны иметь доступа к зоне защемления. Перед реальным запуском требуются закрытые передачи, защита торцов валов, проверка зазоров по всей траектории и работающая блокировка кожуха. Внешний силуэт CAD не является доказательством защищённости всех опасных точек. Испытание щётки выполняется с безопасными макетами и инструментом подачи, без удерживания предмета пальцами перед вращающимися лопастями.

# 06. Сборка, обслуживание и размерные цепи

Сборку начинают с неподвижной рамы на плоском столе. Проверяют диагонали, параллельность продольных элементов и взаимное положение опор ведущей оси. Нельзя компенсировать перекошенную раму регулировкой программного коэффициента левого колеса: это создаёт боковые нагрузки и ухудшает повторяемость движения. Сначала механика должна свободно работать без программной коррекции.

Следующий узел — ведущие валы с опорами. В R01 их положение задано геометрически, но окончательные посадки, стопорение и каталожные подшипники не выбраны. Вал не должен удерживаться от осевого перемещения только трением случайной муфты. Для рабочего выпуска выбирают опорную схему, подшипники, допуски, стопорные элементы и крепёж, после чего обновляют CAD и спецификацию.

Батарею устанавливают на нижнюю опору и фиксируют от смещения во всех направлениях. Упругий ремень не должен перетираться об острый профиль. Провод аккумулятора защищают в месте выхода, главный предохранитель располагают близко к источнику энергии. Передняя механика и контактор ещё обесточены. Мощный аккумулятор не используется как удобный источник для первых опытов с неизвестной платой драйвера.

Ленту собирают как самостоятельный модуль. Проверяют соосность роликов, боковое положение полотна, достаточный диапазон будущего натяжителя и отсутствие контакта планок с неподвижными щитками. В R01 натяжной узел требует детализации; он не должен появляться на настоящей машине «по месту» без отражения в новой ревизии. Непредсказуемое натяжение напрямую меняет ток и нагрев привода.

Бункер опирается на отдельную площадку и извлекается назад. Его наружные размеры 320 × 360 × 220 мм, толщина стенок и дна в геометрической модели — 3 мм. Внутренний объём вычисляется как 314 × 354 × 217 мм³, то есть около 24,12 л. Полезный объём меньше: зона падения, датчик заполнения и неравномерное распределение предметов требуют свободного места.

Рисунок 4. Вид сзади. Для обслуживания сохраняется отдельное направление извлечения бункера.

Окончательную массу и положение центра тяжести проверяют после монтажа проводки. Загруженный бункер может сместить центр тяжести существенно выше и назад. Нельзя считать батарею универсальным противовесом только потому, что она установлена низко. Для проверки устойчивости нужны реальные опорные точки колёс, измеренная масса и медленные стендовые испытания, исключающие неконтролируемое опрокидывание.

Комплект содержит два DXF плоских элементов и эскизный альбом проекций, но не полный набор раскроя и рабочих чертежей всех 121 тел. До изготовления необходимо выпустить спецификацию крепежа, посадок, гибов, способов соединения, натяжителя и защит. Исходная модель полезна именно как согласованная компоновка, которую можно последовательно довести до такого выпуска.

# 07. Электропитание: от батареи до двигателя

Силовая система разделена на логическую и моторную ветви. После главного предохранителя F1 и разъединителя S0 логическая ветвь через F2 питает преобразователь 5,1 В. Моторная ветвь проходит через контактор K1 к общей шине VM_BUS и далее через индивидуальные предохранители к четырём драйверам. Отключение приводов не должно одновременно уничтожать журнал и связь с пультом; поэтому Raspberry Pi питается до K1.

В проекте задан преобразователь с выходом 5,1 В / 5 А и входом, рассчитанным не менее чем на рабочий диапазон батареи. Питание Raspberry Pi 5 заведено через USB-C. В схеме JUSB1 обозначает функциональный интерфейс питания, а не готовую разводку разъёма USB-C с линиями конфигурации. Конкретный источник должен корректно поддерживать требуемый режим питания Pi; одной надписи «5 А» на DC/DC для этого недостаточно. [4]

Номинал батареи 25,6 В не является её максимальным напряжением. Для полностью заряженной 8S-сборки в проектных проверках используется 29,2 В. Напряжение повышается также при возврате энергии от мотора. Поэтому запас по напряжению нужно оценивать для реального режима остановки, а не только для неподвижного заряженного аккумулятора. Входной разъединитель и контактор выбираются с допустимой коммутацией постоянного тока, а не по сходному числу ампер в цепи переменного тока.

В VM_BUS включён конденсатор 10000 мкФ / 50 В. Его энергия при 29,2 В составляет около 4,26 Дж. Подключение незаряженного конденсатора напрямую через контактор может дать большой бросок тока. Для стендовой версии предусмотрен ручной предварительный заряд через 22 Ом: удерживать SPRE не менее 1,2 с, затем выполнить аппаратный ARM и отпустить SPRE. Резистор должен выдерживать импульсную энергию не менее 5 Дж по документации конкретного изделия; фактический режим проверяется измерением.

```text
τ = R·C = 22 · 0,010 = 0,22 с
5τ ≈ 1,10 с
E_C = C·V²/2 ≈ 4,26 Дж при 29,2 В
```

Эта цепь предварительного заряда — ограничение прототипа, а не законченный промышленный автомат. Нажатый SPRE соединяет батарею с моторной шиной через резистор даже при разомкнутом K1. Следовательно, K1 нельзя считать единственным средством безопасного изолирования при обслуживании. Сервис начинается с S0, отключения источника и проверки остаточного напряжения, а не с нажатия экранного STOP.

Разрядный резистор 1 кОм / 2 Вт уменьшает остаточное напряжение, но не делает это мгновенно: постоянная времени с указанной ёмкостью около 10 с. При снятии крышки нельзя полагаться только на истечение условной паузы. Напряжение измеряется на предусмотренных контрольных точках. Также проверяется, не остаётся ли второй путь питания от лабораторного блока или подключённой периферии.

Главный незавершённый вопрос силовой части R01 — гарантированное ограничение рекуперативного перенапряжения. Конденсатор не заменяет расчёт тормозной энергии и зажим напряжения. Надпись «TVS 33 В» сама по себе не обеспечивает предел ниже максимально допустимого для драйвера: важно реальное напряжение ограничения при заданном токе. До движения на батарее необходимо выбрать и испытать решение: управляемое торможение, поглощение энергии, допустимый путь возврата в батарею и защиту при отключении BMS. Прототип без этой проверки не выпускается в моторные испытания.

# 08. Четыре одинаковых канала управления мотором

Два двигателя вращают ведущие колёса; третий приводит щётку; четвёртый — ленту. Для каждого предусмотрен канал на DRV8874 с режимом PH/EN. Направление формируется расширителем SPI, заполнение PWM — внешним генератором I²C. Разделение позволяет Java выдавать медленные команды без программного формирования каждого импульса на GPIO. Драйвер допускает соответствующее управление логическими уровнями, но его пиковый ток нельзя трактовать как гарантированный длительный ток готовой платы. [5]

PCA9685 работает на номинальной частоте около 1017 Гц при выбранном делителе 5 и внутреннем генераторе. Частота не составляет 20 кГц и находится в слышимом диапазоне. Выбор сделан ради простой четырёхканальной реализации. После испытаний её можно изменить только с проверкой диапазона периферии, шумов, нагрева и характеристик мотора. Эта микросхема является генератором PWM, а не силовым драйвером. [6]

Канал 0 — левое колесо, 1 — правое, 2 — щётка, 3 — лента. GPA0…GPA3 MCP23S17 задают PH тех же каналов. Эта нумерация повторяется в Java, схеме, АЦП токов и таблице соединений. Перестановка двух моторов при сохранении старых знаков энкодеров может превратить отрицательную обратную связь в положительную. На стенде каждый канал испытывается отдельно, с вывешенными колёсами и ограниченным источником тока.

Порог аппаратного ограничения тока задаётся VREF. В расчётной схеме принят коэффициент IPROPI 455 мкА/А и резистор 1,5 кОм, что даёт примерно 0,6825 В/А. Делитель 6,19 кОм / 10 кОм формирует около 2,04 В для приводов хода, а 14,3 кОм / 10 кОм — около 1,36 В для механизмов. Получаются ориентиры примерно 3 А и 2 А. Это расчёт настройки, а не измеренная точность ограничения на собранной плате. [5]

Между IPROPI и входом АЦП установлен фильтр 10 кОм / 100 нФ. Он подавляет часть пульсаций, но измеренный сигнал зависит от PWM и режима циркуляции тока. В коде предусмотрены более низкие программные пороги с выдержкой времени. Перед использованием их нужно сопоставить с током, измеренным подходящим прибором, при разных нагрузках. Программное обнаружение заклинивания не заменяет быстродействующее ограничение драйвера.

Конденсаторы зарядового насоса соединяются строго по назначению выводов: 22 нФ между CPH и CPL; 100 нФ между VCP и VM, а не между VCP и землёй. На локальной моторной шине предусмотрены керамический и электролитический конденсаторы. Их наличие в схеме не доказывает, что длинный провод от батареи, индуктивность дорожек и токовая петля будут приемлемы. Печатная плата в R01 не разведена, поэтому тепловая и высокочастотная работа остаётся предметом отдельного проектирования. [5]

При изменении знака команды программный байтовый драйвер сначала отключает PWM, затем меняет PH и возвращает заполнение. Это логическая последовательность, а не доказанная аппаратная пауза переключения транзисторов. Плавность изменения команды дополнительно ограничивает DriveControl. Непосредственное мгновенное реверсирование тяжёлого привода при большой скорости не является допустимым способом аварийной остановки этой версии.

# 09. Аппаратный останов, который не зависит от нейросети

Самая опасная архитектурная ошибка — считать периодическое выполнение отдельного таймера признаком исправности всего управления. Если поток камеры завис, а независимый поток heartbeat продолжает работать, аппаратная сторожевая схема получает ложное подтверждение. В R01 heartbeat меняется только после успешно завершённого цикла чтения, решения и записи приводов. Ошибка обмена или зависание этого пути прекращают подтверждение.

TPS3431 контролирует heartbeat на WDI. Для выбранного включения CWD через 10 кОм к питанию и SET1 в высоком уровне используется номинальный интервал 200 мс с диапазоном порядка 170–230 мс. При цикле 50 Гц GPIO меняет состояние каждые 20 мс, поэтому контролируемые отрицательные фронты следуют примерно каждые 40 мс. Эти числа относятся к проектной конфигурации; фактическую задержку отключения контактора необходимо измерить. [7, 8]

Выход WD_OK проходит через последовательную цепь нормально замкнутых контактов аварийной кнопки, кожуха, бампера и сигнала опасного края. Разрыв любого участка снимает CLEAR_N у триггера SN74LVC1G74. Его Q становится аппаратным разрешением HW_ENABLE. Восстановление контакта или heartbeat не устанавливает Q автоматически: нужен новый положительный фронт на физической кнопке ARM. Удерживаемая кнопка не должна обойти требование повторного пуска. [9]

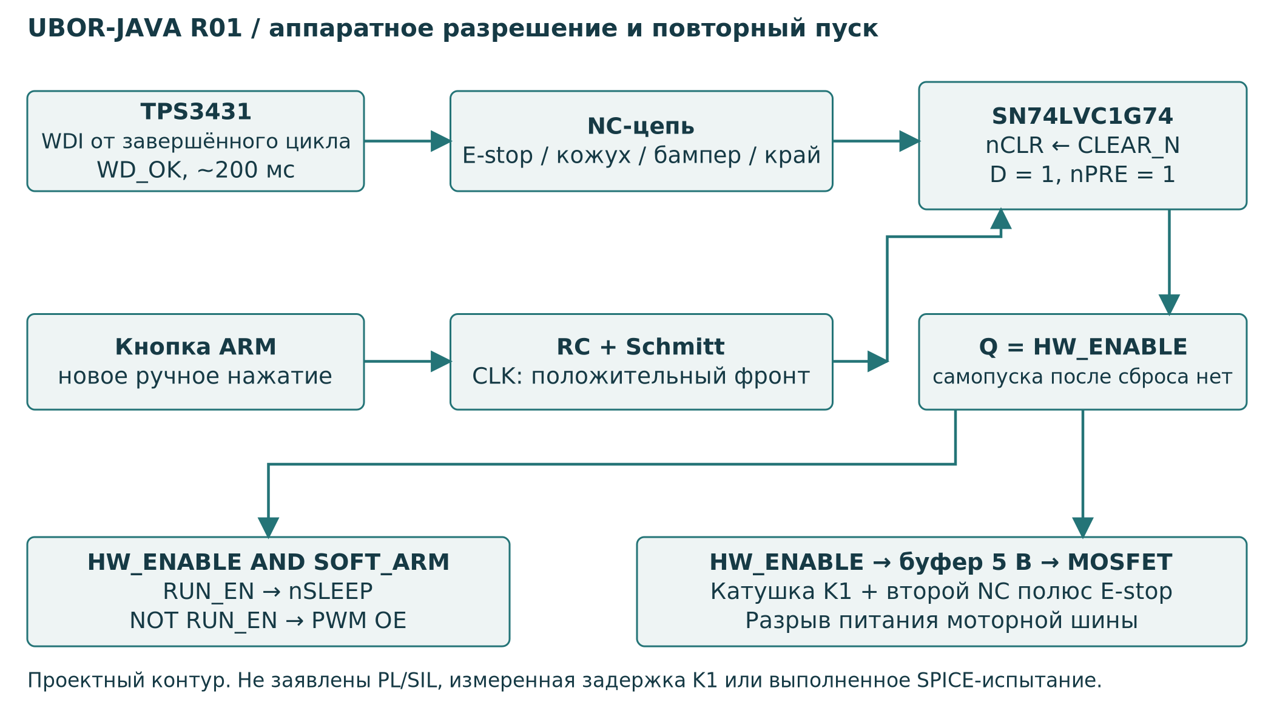
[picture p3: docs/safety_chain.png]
Рисунок 5. Логика разрешения: сброс может возникнуть независимо, восстановление требует нового ручного фронта.


D триггера и неактивный PRE установлены в высокий уровень. Физическая кнопка проходит RC-цепь и триггер Шмитта, чтобы уменьшить влияние дребезга. Начальный сброс использует предусмотренное в сторожевой схеме включение ENOUT. Всё это задано как проект соединений. Переходные процессы включения питания, медленное нарастание 3,3 В, дребезг реальной кнопки и задержка реле не проверялись SPICE или осциллографом и должны войти в стендовый протокол.

HW_ENABLE включает катушку K1 через буфер SN74AHCT1G125 с питанием 5 В и транзистор FQP30N06L. Пятивольтовой амплитуде затвора соответствует документированный режим транзистора; прямое управление этим затвором от GPIO 3,3 В здесь не заявляется как эквивалентное. Диод на катушке подавляет выброс, но может увеличить время отпускания. Это ещё одна причина измерять полную задержку размыкания, а не останавливаться на таймауте watchdog. [10, 11]

Есть и программное разрешение SOFT_ARM. Только логическое И SOFT_ARM с HW_ENABLE формирует RUN_EN для nSLEEP драйверов. Инверсия RUN_EN запрещает выходы PWM через OE. Таким образом, отказ одного программного уровня не должен автоматически разрешить силовой выход. Однако вся схема не имеет заявленного уровня PL/SIL и не заменяет анализ отказов, подходящий для публичной или промышленной эксплуатации.

Контакты, передающие состояние на Pi, должны быть электрически отделены от контактов силового или аппаратного разрешения. Один и тот же физический вывод нельзя одновременно включить в цепь 24 В и подключить к GPIO. Для аварийной кнопки требуются отдельные полюса: разрыв катушки, аппаратная цепь разрешения и считывание состояния. В KiCad эти функции обозначены отдельно; конкретное устройство с нужным количеством контактов ещё нужно выбрать.

# 10. Шины, GPIO и электрические интерфейсы

Каждая линия в `electronics/wiring.csv` имеет имя цепи, обозначение компонента, номер вывода и имя сигнала. Это каноническая таблица соединений. В иерархическом KiCad одинаковые глобальные метки объединяют цепь между листами. Схемы специально самодостаточны по условным символам. Их структурная проверка не равна ERC: выводы абстрактных модулей не несут полной информации о типах питания и допустимых токах.

В заголовке Pi используются физические номера контактов, а в исходниках — BCM. Нельзя перенести число 22 из столбца BCM прямо в номер штырька: GPIO22 находится на физическом контакте 15. Перед монтажом печатают таблицу, маркируют разъём и проверяют каждую цепь прозвонкой при снятом питании. Неиспользуемые контакты питания не соединяют «для надёжности» с другими источниками.

| Функция | BCM | Физический контакт | Сигнал |
|---|---|---|---|
| I²C SDA / SCL | 2 / 3 | 3 / 5 | I2C_SDA / I2C_SCL |
| SPI0 MOSI / MISO | 10 / 9 | 19 / 21 | SPI0_MOSI / SPI0_MISO |
| SPI0 SCLK / CS0 / CS1 | 11 / 8 / 7 | 23 / 24 / 26 | ADC и направления |
| SPI1 MOSI / MISO | 20 / 19 | 38 / 35 | Счётчики энкодеров |
| SPI1 SCLK / CS0 / CS1 | 21 / 18 / 17 | 40 / 12 / 11 | Счётчики энкодеров |
| Heartbeat / Soft arm | 22 / 27 | 15 / 13 | HEARTBEAT / SOFT_ARM |
| Аварийный / Бампер | 23 / 24 | 16 / 18 | ESTOP_SENSE / BUMPER_SENSE |
| Край / Кожух | 25 / 5 | 22 / 29 | CLIFF_SENSE / GUARD_SENSE |
| Заполнение | 6 | 31 | FULL_SENSE |
| Вход / Выгрузка | 12 / 13 | 32 / 33 | INTAKE_BEAM / DROP_BEAM |
| Ошибка драйвера / K1 | 16 / 26 | 36 / 37 | DRV_FAULT_N / K1_SENSE |

Для контактов безопасности нормальное состояние соответствует LOW: исправный нормально замкнутый контакт соединяет вход с землёй, внешний резистор 10 кОм поднимает оборванный вход в HIGH. Ошибка драйвера nFAULT, напротив, активна низким уровнем. Лучевые датчики также дают LOW при прерывании луча. Эти различия отражены в PiHardware, и их нужно проверить на стенде индивидуально.

MCP3008 использует CS0 шины SPI0. CH0 измеряет батарею через делитель 100 кОм / 10 кОм. CH1…CH4 измеряют токи каналов 0…3. CH5 принимает напряжение аналогового дальномера. CH6 и CH7 соединены с землёй. Расширитель MCP23S17 находится на CS1. Его адресные входы зафиксированы в нуле; четыре младших вывода порта A задают направления, остальные входы подтягиваются программно. [12, 13]

Два LS7366R расположены на SPI1 с отдельными CS. Их задача — считать квадратурные импульсы без зависимости от задержки Java-потока. В схеме предусмотрен внешний генератор 1 МГц с логикой 3,3 В. Текущий коэффициент программы — 2048 эффективных отсчётов на оборот колеса после квадратурного умножения. Это требование к выбранному энкодеру и редуктору, а не универсальный параметр любых моторов. [14]

Дальномер задан через интерфейс безопасного напряжения 0…3,3 В. Конкретная модель и характеристика не выбраны. Файл `range-calibration.csv` поэтому пуст: загрузчик отказывается запускать аппаратный режим без измеренной монотонной таблицы. Подстановка правдоподобной кривой чужого датчика была бы хуже честного запрета запуска. Аналогично датчик края должен иметь выбранную и проверенную схему формирования безопасного контакта; одной метки CLIFF в проекте недостаточно для эксплуатации рядом с лестницей.

# 11. Java-ядро: данные, свежесть и состояния

В `Types.java` определены неизменяемые записи команд, датчиков, результата восприятия, решения и сигналов приводов. На входе проверяются диапазоны и конечность чисел. NaN опасен тем, что обычное сравнение может не сработать ожидаемым образом; поэтому недопустимое число отвергается до расчёта PWM. Метки времени получены монотонным таймером, а не календарными часами компьютеров.

У команды есть ограниченное время действия. Командный канал не задаёт режим «ехать, пока когда-нибудь не придёт STOP». Для продолжения движения нужны свежие подтверждения удержания deadman. В R01 срок команды — 200 мс, датчиков — 150 мс, зрения в автоматическом режиме — 250 мс. Эти величины выбраны для прототипа и должны подтверждаться измерениями полной задержки, включая камеру и сетевой тракт.

SafetyController содержит состояния DISARMED, TELEOP, AUTO, COLLECT и FAULT. Он проверяет аппаратные блокировки раньше обычной команды движения. Ряд ошибок фиксируется до явного сброса: аварийный останов, недостоверные или устаревшие датчики, превышение времени цикла, ошибка драйвера, низкое напряжение и длительная перегрузка. Исчезновение причины само по себе не означает разрешение продолжить поездку.

Сброс выполняется при отпущенном deadman и снятой программной команде arm. Отдельно существует физический повторный пуск аппаратного разрешения. Эти два действия не дублируют друг друга: одно относится к состоянию Java-контроллера, второе — к разрешению питания. Пульт не заменяет кнопку аппаратного ARM.

Автоматический режим принимает цель только при достаточной уверенности классификатора. В R01 порог допуска 0,90, порог блокирующей опасной оценки — 0,60. Это начальные инженерные настройки, а не статистически обоснованные пороги безопасности. Их нужно выбирать по отдельной проверочной выборке с учётом цены ошибок, а не по привлекательной точности на обучающем наборе.

Особый переход связан с переносом предмета. До входного луча система ещё принимает решение, подходит ли цель. После подтверждённого входа цель считается принятой, шасси останавливается, щётка выключается, лента довозит предмет до выхода. Если в это время камера увидела следующий объект на полу, его обычная переоценка не должна отменять доставку уже принятого предмета. Но аппаратный аварийный сигнал, недостоверный датчик или другая блокировка продолжает отключать приводы.

Этот переход появился после фактически найденного интеграционного сбоя: распознавание следующего объекта останавливало транспортёр до выгрузки предыдущего. Исправление проверено отдельным утверждением и общим модельным прогоном. Оно показывает пользу явного автомата состояний: причина решения видна в телеметрии, а не скрыта внутри последовательности случайных `if`.

# 12. Запускаем собранный симулятор

Готовый `software/dist/ubor-sim.jar` не требует Pi4J, DL4J, камеры или Maven для запуска. Нужна Java 21. Сначала проверяют `java -version`, затем переходят в каталог `software`. На Windows команды выполняются в PowerShell или терминале IntelliJ. Полный JDK понадобится для пересборки; для запуска уже собранного JAR достаточно подходящей среды выполнения.

```sh
java -version
java -jar dist/ubor-sim.jar --desktop
```

В открывшемся Swing-пульте видны полигон, синтетический вид камеры и телеметрия. Режим явно обозначен SIM_ORACLE_NOT_ML. В симуляторе местоположение и класс предметов берутся из внутреннего состояния мира. Это полезно для отладки управления и переноса, но не является моделью обученного зрения.

Для ручного движения нажимают Arm / Disarm и удерживают SPACE. W или стрелка вверх задаёт движение вперёд; A/D или боковые стрелки — поворот; S — медленное движение назад. Кнопка C включает подбор с выбранной человеком меткой допустимого предмета. При потере фокуса окна сбрасывается разрешение. SPACE не является переключателем: его необходимо держать.

Рисунок 6. Снимок действительно запущенного Swing-пульта под Xvfb: карта, синтетический кадр и телеметрия.

Для воспроизводимого прогона без интерфейса используется команда ниже. Она моделирует 90 секунд, записывает координаты, карты и итоговый JSON. Прогон может выполняться быстрее реального времени, поэтому время симуляции нельзя сравнивать с замером производительности на Raspberry Pi.

```sh
java -jar dist/ubor-sim.jar --demo ../verification/my-demo 90
java -jar dist/ubor-sim.jar --self-test ../verification/my-tests
```

Исходники core/app пересобираются без внешних библиотек. Скрипт выполняет javac, создаёт JAR и запускает проверки. Обычный Maven-проект также подготовлен, но в среде создания данного комплекта Maven и загрузка зависимостей были недоступны. Это означает, что результат офлайн-сборки нельзя объявлять подтверждением полного профиля `full`.

```sh
# Linux / macOS с JDK 21
bash build-offline.sh

# Windows PowerShell с JDK 21
powershell -File build-offline.ps1

# Альтернативная сборка: требует установленный Maven
mvn clean verify
```

Симулятор содержит упрощённую динамику колёс, координаты машины, предметы, лучевые события, перенос по ленте и модель отключения watchdog. Он не рассчитывает деформацию бутылки, контакт всех CAD-поверхностей, ток в транзисторах или реальную инерцию барабана. Сцена из CAD и логический полигон связаны размерами и функциями, но не объединены в физический многотельный решатель.

# 13. Цикл управления и регуляторы колёс

RobotService создаёт отдельный исполнитель для цикла управления с периодом 20 мс. В одном успешном проходе он читает аппаратные входы, получает актуальную команду и последний результат восприятия, вычисляет решение, формирует воздействия и записывает их в аппаратный интерфейс. Только после удачного завершения записи меняется heartbeat. Запись PNG, отправка предпросмотра и нейросеть не выполняются в этом потоке.

Вторая задача отвечает за кадры, инференс и запись учебных данных. Она может работать медленнее 50 Гц: управляющий поток пользуется последним результатом, пока он достаточно свеж. Если камера или сеть задержалась настолько, что результат устарел, автоматический режим останавливается. Так устраняется требование ждать окончания нейросети перед каждым решением о состоянии приводов.

В модели датчики получают монотонную метку времени. В аппаратном адаптере чтение шин занимает ненулевое время, поэтому отметка берётся консервативно относительно начала чтения. Для команды время задаёт принимающая сторона. Не требуется синхронизировать календарные часы пульта и Pi для проверки lease; системное изменение времени или разный часовой пояс не должны продлить старую команду.

Дифференциальная кинематика для колеи B = 0,5 м записывается так:

```text
v_left  = v − ω·B/2
v_right = v + ω·B/2
Ω_left  = v_left / r
Ω_right = v_right / r
```

DriveControl сочетает предварительную оценку заполнения по скорости и PI-коррекцию по энкодерам. Интегральная составляющая ограничена, чтобы не накапливать огромную ошибку при насыщении. Скорость изменения воздействия также ограничена. При запрете движения выход выключается непосредственно; обычное плавное снижение команды не должно задерживать аварийный запрет.

Параметры регулятора — начальная настройка для прототипа, не результаты идентификации выбранного мотора. На вывешенном колесе проверяют знак, затем малую скорость и переходный процесс. На полу повторяют измерение с пустым и нагруженным бункером. Слишком большие коэффициенты могут дать колебание, а слишком маленькие — заметное отклонение и плохой поворот. Уменьшение колебаний программным фильтром не оправдывает неправильный знак обратной связи.

Отдельный незавершённый пункт R01 — диагностика правдоподобия энкодера. Байт счётчика корректно читается и переполнение учитывается, но полноценный контроль оборванной линии, невозможного скачка и несоответствия движению ещё не реализован. До реальных автоматических поездок нужно добавить и испытать такой монитор. Исправный SPI-пакет со счётчиком ноль не доказывает неподвижность колеса.

При исключении аппаратного обмена управляющий цикл прекращает обновление heartbeat, пытается выключить выходы и фиксирует ошибку. Нельзя обещать, что попытка программного отключения обязательно дойдёт по неисправной шине. Поэтому независимый watchdog является частью конструкции, а не дополнительным удобством. Ни наличие ScheduledExecutorService, ни выбор Java 21 не превращают Linux в систему жёсткого реального времени.

# 14. Пульт, геймпад и управление по сети

Пульт написан на Java Swing. Один сеанс оператора использует TCP: сервер выдаёт случайный challenge, клиент подписывает команды HMAC-SHA256. Порядковый номер защищает от повторения старого пакета в том же сеансе, challenge — от переноса пакета в новый. Протокол ограничивает размеры сообщений и отвергает неполные или повреждённые данные.

Подписана именно команда управления. Телеметрия и JPEG-предпросмотр не защищены отдельной криптографической подписью и не шифруются. Поэтому этот протокол не предназначен для открытого Интернета. На прототипе используется изолированная доверенная сеть. Для реального сетевого продукта потребуются аутентифицированное шифрование, управление ключами, политика доступа и анализ отказов. Слово HMAC не означает, что все сетевые риски уже устранены.

Секрет не зашит в исходники. Утилита генерирует новый случайный ключ; одно и то же значение задаётся через UBOR_KEY на машине и пульте. Генерировать разные ключи независимо на двух сторонах нельзя: связь закономерно не пройдёт проверку. Ключ не записывается в репозиторий и не прикладывается к публичному отчёту.

```sh
# На одной стороне, затем безопасно передать значение другой
java -jar dist/ubor-sim.jar --new-key

# В обоих терминалах задать ОДИН и тот же полученный секрет
export UBOR_KEY='сюда_сгенерированное_значение'

# Сервер-симулятор
java -jar dist/ubor-sim.jar --server-sim 9090

# Пульт на другом компьютере
java -jar dist/ubor-sim.jar --controller 192.168.10.20 9090
```

В PowerShell переменная задаётся как `$env:UBOR_KEY='...'`. Пульт обновляет команды примерно 20 раз в секунду. Сервер не сохраняет разрешение бесконечно: отсутствие действительного пакета закрывает сеанс, а короткая аренда команды в контроллере служит дополнительным ограничителем. Автоматического переподключения с восстановлением ARM нет. После потери связи оператор должен заново установить управление.

Для Linux реализован чтение устройства `/dev/input/js0` непосредственно в Java: 8-байтовые события joydev разбираются с нужным порядком байтов. Используются оси 0 и 1, кнопка 4 — deadman, 0 — arm без удержанного deadman, 1 — disarm, 2 — переключение AUTO без deadman, 3 — STOP, 6 — сброс. Инициализационные события не должны сами включать машину. Эта раскладка является проектной; конкретный USB-геймпад физически не испытан. [15]

```sh
java -jar dist/ubor-sim.jar \
  --gamepad 192.168.10.20 9090 /dev/input/js0
```

Геймпад в текущей версии не имеет интерфейса ручной разметки объекта и ручного запуска подборщика с меткой. Для таких действий используется Swing-пульт. Автоматический подбор с геймпада возможен только в режиме с допущенной моделью или в явно обозначенном oracle-симуляторе. Показанный на экране STOP полезен, но остаётся сетевой командой и не заменяет физическую кнопку на машине.

# 15. Pi4J: от Java-объекта к байтам на проводе

Pi4J 3.0.4 выбран сознательно, а не как автоматически «самая новая версия». Ветка 3 требует Java 21; выпуск 3.0.4 содержит исправление границ цикла SPI. Более новая ветка 4 имеет другой базовый уровень Java. При выпуске изделия версии фиксируют вместе, а обновление проводят как отдельное изменение с повторным стендовым тестом. [1]

Аппаратный модуль использует GpioD для цифровых линий и LinuxFS для SPI/I²C. В PiHardware собираются конфигурации соответствующих устройств. Однако доступность `/dev/spidev...`, нумерация GPIO chip и права зависят от реально установленной ОС. Одного наличия JAR недостаточно: интерфейсы нужно включить и проверить в системе, а пользователя сервиса включить в необходимые группы. В этой среде такие проверки на Pi не проводились. [2]

Байтовые драйверы находятся в независимом `RegisterDevices.java`. Например, чтение канала MCP3008 выполняется трёхбайтовой транзакцией. Такое разделение позволяет тестировать формирование команды без электрической платы:

```java
byte[] rx = bus.transfer(new byte[]{
    1, (byte)((8 + channel) << 4), 0
});
int value = ((rx[1] & 3) << 8) | (rx[2] & 255);
```

Здесь `& 255` устраняет знаковую интерпретацию Java-байта. Тест подтверждает порядок байтов и декодирование, но не частоту SPI, корректность уровней или отсутствие наводки. На первом стенде логическим анализатором сверяют CS, SCLK, MOSI и MISO с ожидаемой последовательностью. Подключение правильного устройства к неправильному CS может давать правдоподобные нули, поэтому проверяют каждый канал независимо.

Для PCA9685 важна особенность общей записи ALL_LED: это не независимый «главный разрешающий бит», который можно свободно очищать после индивидуальных каналов. Общая запись влияет на регистры каналов. В R01 после записи отдельных заполнений не выполняется дополнительное очистительное действие ALL_LED, которое могло бы испортить уже записанные значения. Эта последовательность выделена в отдельную проверку. [6]

LS7366R отдаёт четырёхбайтовый счётчик старшим байтом вперёд. При накоплении перемещения намеренно используется знаковая 32-битная разность для обработки переполнения. Чтобы это было корректно, между чтениями не должно пройти более половины диапазона счётчика. На скоростях R01 это большой запас, но само математическое предположение всё равно следует понимать, особенно при изменении частоты энкодера. [14]

Конфигурация блокирует аппаратный запуск до калибровки. Значения motor.sign и encoder.sign должны быть ±1 и соответствовать проверенному направлению. Таблица дальномера должна содержать не менее четырёх реально измеренных монотонных точек. Для автоматического зрения отдельно проверяется camera.calibration.complete. Эти флаги служат запретом преждевременного запуска, но не способны проверить, действительно ли человек выполнил измерения: ответственность за процедуру остаётся у выпускающего инженера.

# 16. Камера, координаты и границы машинного зрения

В R01 выбрана UVC-камера с доступом через JavaCV/OpenCV. Начальная конфигурация — 640 × 360 при запрошенных 15 кадрах/с. Запрошенный режим не означает гарантированную частоту конкретной камеры: драйвер может согласовать другой формат, а очередь кадров может добавить задержку. Проверяется фактическое изображение и время между событием перед камерой и доступностью соответствующего кадра в Java.

Предобработка одинакова при обучении и эксплуатации: RGB, размер 64 × 64, float в диапазоне 0…1, порядок NCHW. Несогласованность RGB/BGR или другой масштаб входа может разрушить результат без исключения в программе. Поэтому преобразование вынесено в один класс Images, а формат записывается в метаданные модели.

Для локализации применяется базовый алгоритм скользящих окон двух масштабов в нижней области изображения. Каждое окно передаётся классификатору. Выбирается допустимый кандидат с лучшей оценкой; опасная оценка блокирует движение. Это не YOLO, не сегментация экземпляров и не полноценный детектор с регрессией координат. Крупная бутылка может попадать сразу в несколько окон, а часть фона — давать высокую уверенность по ошибке.

Начальная локализация использует нижнюю точку окна и пересечение соответствующего луча с плоскостью пола. Для этого нужны фокусные расстояния fx/fy, главная точка cx/cy, высота камеры, угол наклона и смещение до приёмного окна. Числа в `robot.properties` — оценки компоновки, не калибровка. На настоящей машине сначала измеряют внутренние параметры и искажения, затем внешний наклон и положение относительно пола.

Рассуждение о проекции простое: один пиксель задаёт луч, а плоскость пола выбирает на луче конкретную точку. Если предмет находится не на полу, а на ступени или верхняя часть бутылки используется вместо точки контакта, предположение нарушается. Поэтому в R01 не обещана точность геометрической локализации, достаточная для любого размера мусора. Её нужно измерить на разметке пола вблизи подборщика.

Классификатор и модель движения решают разные задачи. Классификатор получает вырезку предмета и отвечает классом. Модель движения получает полный кадр и предлагает v и ω, обучаясь по действиям человека. Нельзя обучить полнокадровую модель на маленьких вырезках и ожидать, что она поймёт маршрут. Также нельзя переносить метку «бумага» на весь сложный кадр, где одновременно находятся несколько объектов.

Высокая softmax-оценка не является гарантией распознавания неизвестного типа отхода. Класс UNKNOWN полезен как обучаемая категория примеров, но не решает автоматически проблему всех неизвестных изображений. Для реального выпуска требуется отдельно измерить ложные разрешения на неподходящих предметах, влияние бликов, теней, цвета пола, собственной щётки в кадре и частично скрытых объектов. До этого AUTO остаётся лабораторным режимом под непосредственным наблюдением.

# 17. Сбор данных при объездке

Возникает естественный вопрос: как получить первые данные, если аппаратный AUTO требует обученную модель? Для этого предусмотрен режим `--hardware-teleop`. Он использует настоящую камеру и ручное управление, но не требует весов нейросети. Аппаратная калибровка, блокировки и внешний watchdog при этом по-прежнему необходимы. Разница только в том, кто предлагает движение.

```sh
# После аппаратной проверки и сборки полного classpath
java -cp 'dist/full/*' com.ubor.app.Main \
  --hardware-teleop config/robot.properties 9090 ../data/run_01
```

DatasetRecorder сохраняет PNG и manifest.csv из потока камеры, а не из управляющего цикла. Запись допускается только при ручном режиме, удержанном deadman и действительном разрешении движения. Разница отметок кадра и команды должна быть не более 100 мс. Это необходимая начальная проверка согласования, но не измерение задержки экспозиции и очереди видеодрайвера.

Манифест содержит путь изображения, выборку, метку, применённые v/ω, идентификатор сеанса, времена кадра и команды, исходно запрошенные скорости и причину решения. В обучении движения используются применённые команды: если SafetyController ограничил скорость, нельзя незаметно записать в качестве правильного действия запрещённую исходную величину. В то же время такие данные могут содержать остановки из-за блокировки; их смысл необходимо разбирать при формировании учебной задачи.

```text
image,split,label,v,w,session,...
images/run01_000123.png,unassigned,PAPER,0.08,0.00,run01,...
```

Метка выбора оператора — не готовая разметка всех объектов кадра. Для классификатора дополнительно размечают прямоугольники. Утилита DatasetTool умеет вырезать их по CSV с полями image,x,y,width,height,label,session,split. Графического редактора прямоугольников в комплекте нет: разметку выполняют отдельно и передают таблицу. Координаты проверяются на выход за границы, пути — на выход из корня набора.

```sh
java -cp dist/ubor-sim.jar com.ubor.app.DatasetTool \
  crop ../data/raw ../data/boxes.csv ../data/crops
```

Для первоначального объезда заранее раскладывают безопасные предметы, выбирают понятный маршрут и избегают смешения нескольких задач в одном сеансе. Полезно отдельно записывать подъезд, небольшое боковое отклонение, остановку без предмета и контролируемый отказ. Не нужно собирать данные движением на опасные отходы: для отказов достаточно безопасных макетов и обычных неподходящих предметов, не создающих угрозы механике.

Важна и отрицательная выборка: чистый пол, собственный бампер, полоска тени, край коврика. Набор из одних центрированных бутылок учит распознавать демонстрационную композицию, а не работать на машине. Для каждой записи сохраняют условия: покрытие, свет, расположение камеры, версию механики и настройки. После изменения высоты камеры нельзя автоматически объединять новую съёмку со старой без проверки совместимости.

# 18. Разбиение, обучение и оценка DL4J

Соседние кадры одного объезда очень похожи. Если случайно распределить их между обучением и тестом, модель фактически увидит почти те же сцены при проверке. Поэтому разделение проводится целыми сеансами. Все кадры одного session относятся только к train, val или test. Manifest проверяет это условие и отвергает повторное использование изображения.

Исходный рекордер намеренно пишет `unassigned`. Человек создаёт таблицу session,split. DatasetTool переносит выбранную принадлежность в новый манифест. Новый файл следует размещать рядом с деревом его изображений: загрузчик ML не допускает путей, выходящих за корень манифеста. Для объединённого датасета сначала организуют единый каталог изображений и сохраняют относительные пути без запятых.

```sh
java -cp dist/ubor-sim.jar com.ubor.app.DatasetTool \
  split ../data/raw/manifest.csv config/sessions.csv \
  ../data/raw/manifest.split.csv
```

Сеть в Networks — небольшой CNN: свёртка 5 × 5 с шагом 2 и 16 каналами, pooling, свёртка 3 × 3 с 32 каналами, глобальное усреднение, Dense 64 и выход. Для классификатора выход имеет шесть softmax-компонент и функцию потерь классификации; для модели движения — две tanh-компоненты и MSE. Это стартовая архитектура, а не результат сравнительного исследования нескольких моделей.

Trainer написан на Java, работает с мини-пакетами по восемь примеров, перемешивает только обучающую выборку, сохраняет лучший checkpoint по validation loss и затем отдельно оценивает test. Для классификатора требуется наличие всех классов в train. Для каждого выпуска записываются кривая обучения, метаданные, SHA-256, тестовая матрица ошибок либо MAE скорости и поворота.

```sh
# Требуются внешние зависимости и успешный native preflight
java -cp 'dist/full/*' com.ubor.ml.Trainer classifier \
  ../data/crops/manifest.csv ../models/classifier.zip 30

java -cp 'dist/full/*' com.ubor.ml.Trainer policy \
  ../data/raw/manifest.split.csv ../models/policy.zip 30
```

Число 30 здесь — пример числа эпох для запуска, а не найденный оптимум. Выбор checkpoint производится по валидации, но чрезмерное многократное использование одной валидационной выборки также приводит к подгонке эксперимента. Финальный тест нельзя использовать как ещё один набор для регулярной настройки порогов.

Для классификации важны не только общая accuracy и macro-F1, но и конкретные ошибки: сколько опасных макетов ошибочно признано бутылками, сколько бумаги пропущено на тёмном полу, сколько чистых окон объявлено мусором. В отчёте R01 отсутствующий класс в test помечается как неопределённый recall; это не ноль риска. Для модели движения MAE — вспомогательная метрика: небольшая средняя ошибка может скрывать один резкий опасный поворот.

Код обучения включён, но зависимости DL4J в этой среде не загружались, сети не обучались и реальных метрик нет. Любые числа точности до эксперимента были бы выдумкой. Файлы модели после обучения получают `approved.for.hardware=false`. Одобрение выполняется только после отдельной проверки изображений, локализации, временных задержек, соответствия классов и стендовых действий. Сам факт завершения `Trainer` не является разрешением двигаться.

# 19. Перенос ML на Raspberry Pi и проверка задержек

DL4J предоставляет Java-интерфейс, но вычисления ND4J используют нативный backend. Поэтому успешная компиляция Java на настольном компьютере ещё не доказывает загрузку численной библиотеки на Linux ARM64. В R01 закреплены DL4J/ND4J 1.0.0-M2.1 и JavaCV 1.5.7 с соответствующей линией OpenCV. Комбинация Java 21, выбранной ОС и ARM-зависимостей здесь не испытана; это самостоятельный этап допуска. [3, 16]

Полная сборка выполняется из `software`. Скрипт собирает все модули и копирует runtime-зависимости в `dist/full`. В отличие от компактного симулятора, этот каталог может быть большим из-за нативных платформенных библиотек. Для промышленного выпуска разумно оставить только нужные платформы после успешной проверки, но нельзя удалять артефакт, ориентируясь только на похожее название.

```sh
bash assemble-full.sh
java -cp 'dist/full/*' com.ubor.ml.Preflight
```

Preflight создаёт небольшой CNN и выполняет серию прямых проходов, выводя времена. Его цель — обнаружить проблему загрузки ND4J и получить начальное представление о задержке. Он не измеряет получение кадра, скользящие окна, нейросеть движения, запись диска, шину и реакцию контактора в сумме. Нельзя взять напечатанную медиану и назвать её задержкой всей машины.

Для полноценного временного испытания создают контролируемое визуальное событие и одновременно регистрируют соответствующий физический сигнал. Затем сопоставляют момент события, доступность кадра, окончание инференса, решение контроллера, запись PWM и остановку движения. Важно измерять хвост распределения, а не только среднее. Редкая длинная пауза GC или задержка камеры может быть важнее большинства быстрых кадров.

В текущем контроллере результат зрения старше 250 мс не используется для автоматического движения. При медленном скользящем окне машина будет останавливаться, что лучше скрытого движения по старой картинке, но может сделать концепцию практически бесполезной. Тогда сначала профилируют, уменьшают число кандидатов, меняют архитектуру или используют более подходящий детектор. Простое увеличение допустимого возраста кадра без пересчёта остановки не является исправлением производительности.

Для CNN недостаточно оценить frames per second. При 0,20 м/с задержка 0,25 с соответствует 5 см движения ещё до исполнительного торможения. Если окно локализации ошибается на сопоставимую величину, губа может уже пройти нужную точку. Нужна совместная таблица ошибок: позиция объекта, угол подхода, освещение, возраст кадра, скорость и исход подбора.

Сервис systemd приведён как шаблон. Он запускается от отдельного пользователя, получает секрет из отдельного файла и имеет `Restart=no`, чтобы не восстанавливать бортовое приложение после отказа незаметно для оператора. Порт шаблона — 8844; примеры ручного запуска используют 9090, поэтому пульт должен подключаться к фактически выбранному порту. До установки сервиса аппаратный вариант запускают вручную на стенде и фиксируют версии всех компонентов.

# 20. Что показывают фактические проверки R01

В переданном комплекте выполнена настоящая офлайн-компиляция модулей core/app на Java 21.0.11. Собран JAR, запущены 50 именованных автоматических утверждений. Проверяются свежесть команд, отклонение NaN, диапазоны приводов, блокировки, фиксация отказов, ручной сброс, таймауты, переходы подбора, HMAC, защита от повторов, байтовые команды и отдельные свойства симулятора.

| Проверка | Фактический результат | Граница результата |
|---|---|---|
| core/app javac и JAR | Выполнено успешно | Без Pi4J/DL4J |
| SelfTest | 50 утверждений пройдены | Логика и модель, не физическая безопасность |
| TCP loopback | 40 подписанных обменов | Не радиоканал на реальной площадке |
| Потеря сеанса | Отключение наблюдалось после паузы 300 мс | Не точное измерение времени остановки |
| Модельный подбор | 3 предмета, 1 опасный оставлен | Oracle, не нейросеть |
| STEP round trip | 121 валидное тело | Не FEA и не полный collision check |
| Электрический граф | 141 компонент, 100 цепей | Не KiCad ERC, не SPICE и не плата |
| Swing GUI | Запуск и снимок экрана | Не полное тестирование действий пользователя |

Сетевой тест использует настоящий сокет loopback, а не вызов метода контроллера вместо сети. Он отправляет 40 HMAC-команд, читает телеметрию и проверяет, что корректные команды разрешали модельные приводы. Затем соединение закрывается, и через 300 мс проверяется запрет. Сам тест честно отмечает, что эта пауза наблюдения не определяет точную задержку выключения.

Модельный прогон длится 90 секунд симулированного времени. Его итог: collected = 3, remaining = 1, last_reason = HAZARD_VISION_STOP. Координаты и события записаны в trajectory.csv, карты — в PNG. Поле mode явно содержит SIM_ORACLE_NOT_ML, а поля physical_hardware и electrical_circuit_simulation равны false. Эти признаки нужны, чтобы отчёт нельзя было случайно принять за полевой эксперимент.

Рисунок 7. Итог модельного прогона: допускаемые предметы убраны, опасная цель осталась.

Для CAD выполнен повторный импорт STEP через геометрическое ядро и проверено число валидных тел. Для электроники проверены уникальность обозначений и номеров выводов, отсутствие моторной шины на GPIO, соответствие четырёх моторных каналов, соединение конденсатора VCP с VM и баланс синтаксических скобок KiCad-файлов. Не найдено цепей только с одним концом. Эти проверки полезны, но не понимают всех физических причин отказа.

Не выполнены загрузка и запуск KiCad, ERC, разводка PCB, SPICE, испытания GPIO, SPI на настоящем Pi, камера UVC, USB-геймпад, обучение DL4J, ARM native preflight и механические испытания. В книге и README это не спрятано за словом «готово». Готовыми здесь являются переданные исходники, CAD-геометрия, компактный исполняемый симулятор и перечисленные отчёты, а не физически испытанное изделие.

# 21. Стендовый ввод: последовательность разрешений

Стендовый ввод нельзя начинать с полностью собранной машины на полу и команды AUTO. Сначала должна появиться уверенность в каждом барьере, который удерживает систему от непреднамеренного движения. Работы проводят специалистом на ограждённом стенде, с доступным физическим отключением и безопасными макетами. Лабораторный источник с ограничением тока на ранних этапах предпочтительнее аккумулятора с большим доступным током.

Этап A — механическая и электрическая проверка без питания. Сверяют фактические детали с CAD, крепёж и стопорение валов, свободу вращения, защиту ремня и щётки, маршрут проводов. Проверяют полярность, отсутствие коротких замыканий, соответствие контактов разъёма и раздельность полюсов аварийной кнопки. Любая неподтверждённая соединительная колодка останавливает ввод, а не получает временную перемычку.

Этап B — логика без подключённых моторов. Проверяют 5,1 В и 3,3 В, начальный запрет RUN_EN, работу watchdog и ручного фронтового пуска. Отдельно имитируют удерживаемый ARM, исчезновение heartbeat, выключение питания, восстановление питания и открытый контакт кожуха. Разрешение не должно возвращаться автоматически после устранения причины. Сигнал K1_SENSE сверяют с настоящим состоянием контактора, а не только с напряжением катушки.

Этап C — силовая плата на ограниченном источнике. Проверяют форму PWM, направления, токовый сигнал и отключение nSLEEP. Измеряют бросок при предварительном заряде, отпускание контактора и напряжение VM при остановке. Пока не выбрано и испытано ограничение рекуперации, переход к энергичной нагрузке и батарее запрещён. Нагрев оценивается после выдержки режима, а не касанием платы через несколько секунд.

Этап D — вывешенные колёса, минимальные воздействия. Определяют знаки каждого двигателя и энкодера, измеряют число отсчётов на оборот колеса и проверяют нулевой выход при снятии разрешения. Здесь же нужна добавленная диагностика энкодерных отказов. Двигатели щётки и ленты ещё отключены. Неправильный знак обнаруживают до включения регулятора с существенным усилением.

Этап E — калибровка датчиков и остановки. Дальномер измеряют на нескольких известных расстояниях и материалах, выбирая монотонный рабочий диапазон. Проверяют контактные входы, лучи, датчик заполнения и край. Физический дальномер в компоновке расположен высоко; он не гарантирует обнаружение низких препятствий. Требуется согласовать его поле зрения с допустимым мусором и отдельно оценить слепую нижнюю зону. На R01 это дополнительное ограничение ограждённого полигона, а не разрешение игнорировать низкие препятствия.

Этап F — ручная езда на полу без подбора. Проверяют пульт, отпускание deadman, разрыв сети, выключение клиента, потерю фокуса и задержки. Затем отдельно запускают механизм приёма с безопасными предметами. В AUTO переходят только после проверки данных, моделей, калибровки камеры и полного временного тракта. На каждом этапе сохраняют таблицу: версия, дата, условия, ожидаемое событие, измеренный результат и решение о переходе дальше.

# 22. Остановка и геометрический запас

Остановка — это сумма задержек и пути выбега. Если пропала команда, сначала истекает время её действия; затем выполняется решение или срабатывает аппаратный watchdog; затем снимается воздействие и механика замедляется. Электрическое отключение не равно мгновенной нулевой скорости. На склоне оно вообще не гарантирует удержание положения без отдельного тормоза.

Для предварительной оценки приняты v = 0,30 м/с, суммарная задержка 0,30 с, замедление 0,60 м/с² и геометрический запас 0,10 м. Эти величины не измерены. Получается:

```text
s = v·t + v²/(2·a) + запас
s = 0,30·0,30 + 0,30²/(2·0,60) + 0,10
s ≈ 0,265 м
```

В контроллере порог препятствия задан 0,35 м. Сопоставление 0,265 и 0,35 полезно только при одинаковой точке отсчёта. Если дальномер расположен позади передней кромки щётки, его измеренное расстояние до препятствия нужно преобразовать к реальной выступающей части машины. В R01 такой геометрический вопрос должен быть разрешён измеренной калибровкой и расположением датчика, а не вычитанием произвольной величины из результата.

При полном бункере, другом покрытии, влажной поверхности или снижении сцепления фактический путь изменится. Если моторный драйвер в запрещённом состоянии даёт свободный выбег, расчёт с сильным активным торможением неверен. На стенде измеряют именно реализованный способ останова и его отказные варианты. Параметр `deceleration` логического симулятора не переносится в технический паспорт.

Отдельно проверяют остановку ленты и щётки. После выключения питания они сохраняют вращательную энергию, а гибкие лопасти могут продолжать двигаться. Размыкание кожуха должно запрещать дальнейшее приведение в движение, но безопасный доступ к механизму требует учёта остаточного движения. Для R01 режим обслуживания предполагает полное отключение, ожидание неподвижности и проверку остаточного напряжения.

У робота нет отдельного механического удерживающего тормоза и нет заявленной безопасной эксплуатации на уклоне после аварийного снятия питания. Поэтому расчёт 5° в главе 4 нельзя читать как гарантию остановки и удержания на пандусе. Если такая функция нужна, придётся добавить тормоз, датчик его состояния, управляющую схему и новые тесты, а также обновить CAD и массу.
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

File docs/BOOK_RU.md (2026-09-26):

# Предисловие. От идеи к проверяемой машине

Робот, который узнаёт бутылку на фотографии, и робот, который доставляет эту бутылку в бункер, — разные устройства. Между ними лежат геометрия входного окна, сцепление колёс, ток двигателя, задержка камеры, состояние ленты и решение оператора. Эта книга описывает один связанный проект, а не коллекцию независимых примеров. Его имя — UBOR-JAVA R01.

Проект создан для проверки идеи на закрытом полигоне. Он включает настоящую твердотельную CAD-модель, схему соединений электроники, исходный Java-проект, запускаемый симулятор и код обучения. При этом физический робот ещё не построен, аппаратные модули не прошли проверку на Raspberry Pi, а обученных весов в комплекте нет. Эти границы важны: хороший инженерный прототип начинается с возможности точно сказать, что уже проверено, а что пока является гипотезой.

Слово «прошивка» здесь используется в бытовом смысле бортового программного обеспечения. Самостоятельной платы с STM32 и программой на C в R01 нет. На Raspberry Pi работает Java-процесс, который читает датчики, формирует команды приводам, принимает пульт и вызывает нейросети. Таймер PWM, аппаратные счётчики энкодеров и сторожевой таймер выполняются покупными микросхемами без нашей микропрограммы. Linux, JVM и численные библиотеки, разумеется, не переписываются на Java.

В книге последовательно разделены расчёт, программа и эксперимент. Например, расчётная тяга 3,15 Н·м на колесо не является измеренным моментом выбранного мотора; успешный TCP-тест не означает испытанную радиосвязь на улице; три собранных предмета в симуляторе не доказывают качество машинного зрения. Такое разделение позволяет дорабатывать проект без потери доверия к его результатам.

Основной маршрут чтения: сначала область применения и архитектура, затем механика и электрическая часть, после этого Java, обучение и стендовый выпуск. Тем, кто хочет немедленно увидеть работающую программу, достаточно открыть главу 12. Книга сопровождает конкретные файлы R01: названия классов и команд соответствуют исходникам в архиве.

> Статус издания: инженерный proof of concept, 23 сентября 2026 года. Не рабочая документация для немедленного изготовления, не руководство по эксплуатации сертифицированного изделия.

Рисунок 1. Общий вид, программно полученный из той же CAD-сборки, которая передаётся в STEP.
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

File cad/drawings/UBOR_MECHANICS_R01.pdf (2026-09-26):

## М01 / Общая компоновка и единый CAD-источник

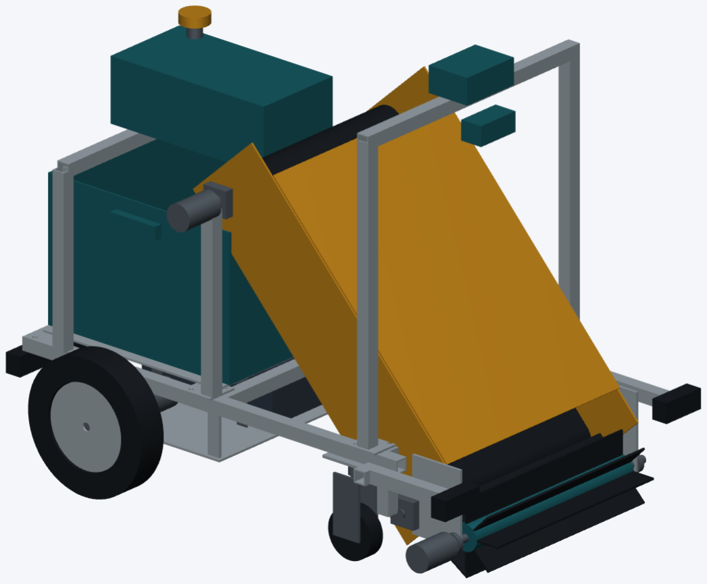
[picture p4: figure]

UBOR-JAVA R01 · ЭСКИЗНЫЙ ПРОЕКТ · не для изготовления

CAD: CadQuery / OpenCascade. Размеры в мм. Изображения не задают масштаб печати.

Лист 1/5 | 23.09.2026

121 именованное твердотельное тело.

Габарит STEP: 809,5 × 545,0 × 665,0.

Рама: 660 × 430; профиль 20 × 20 × 2.

Колёса Ø200; колея 500.

Рабочая ширина: 320.

Бункер: 24,12 л; полезная нагрузка до 4 кг.

Расчётная полная масса: 30 кг.

Оценка массы модели: 24,31 кг.

STEP + отдельные детали + параметрический исходник. Нативные SolidWorks-файлы не созданы.
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

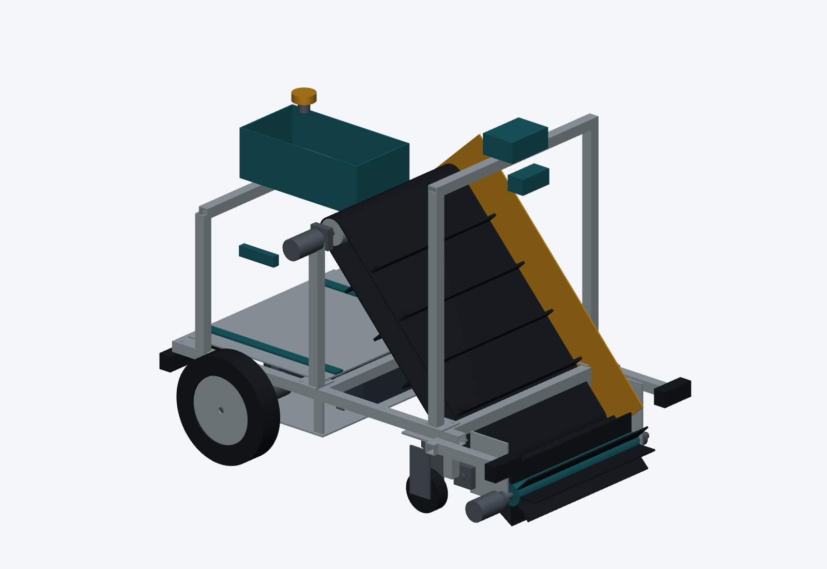
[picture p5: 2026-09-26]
cad/render/cutaway.png

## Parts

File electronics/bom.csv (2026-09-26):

reference | value_or_procurement_requirement | quantity | sheet | notes
BT1 | 8S LiFePO4 / BMS / 25.6V 10Ah | 1 | 01_power | Assembled protected pack; charger external; no cell assembly instructions
F1 | 15A DC fuse / near pack | 1 | 01_power
S0 | Main DC disconnect | 1 | 01_power
F2 | 3A logic branch | 1 | 01_power
PS1 | Regulated 5.1V / 5A converter | 1 | 01_power | Input >=36V; Pi5 compatible USB-C power/advertisement; verify undervoltage
JUSB1 | Pi5 USB-C power interface | 1 | 01_power | Abstract power connector, NOT a USB-C receptacle footprint or CC wiring
K1 | 24V DC contactor + isolated feedback | 1 | 01_power | Select >=30V DC breaking rating >=15A; auxiliary contact required; pin numbers are interface labels
S1B | E-STOP second NC pole | 1 | 01_power
Q1 | FQP30N06L / TO-220 | 1 | 01_power | Driven by 5V AHCT buffer, not directly by 3.3V GPIO
D1 | 1N4007 coil diode | 1 | 01_power | Measure added release delay; cathode at coil+
RG1 | 100R gate | 1 | 01_power
RGS1 | 100k gate pulldown | 1 | 01_power
CBULK | 10000uF / 50V low-ESR | 1 | 01_power | Bus energy buffer, NOT validated regenerative clamp
RBLEED | 1k / 2W | 1 | 01_power | Discharge time is tens of seconds; measure voltage before service
SPRE | Momentary PRECHARGE only | 1 | 01_power
RPRE | 22R / pulse >=5J | 1 | 01_power | Hold >=1.2 s before physical ARM; release after ARM. Validate inrush and contacts.
RVTOP | 100k / 0.1% | 1 | 01_power
RVBOT | 10k / 0.1% | 1 | 01_power
CV | 10nF | 1 | 01_power
UWD | TPS3431 DRB | 1 | 02_watchdog | CWD pull-up 10k: timeout nominal200ms,170..230ms; ENOUT tied to WDO
RCWD | 10k | 1 | 02_watchdog
RWDO | 10k | 1 | 02_watchdog
RWD_PD | 100k | 1 | 02_watchdog
S1A | E-STOP NC auxiliary | 1 | 02_watchdog
S3A | Guard NC | 1 | 02_watchdog
S4A | Bumper NC | 1 | 02_watchdog
S5A | Cliff relay NC | 1 | 02_watchdog
RCLR | 100k | 1 | 02_watchdog
UFF | SN74LVC1G74 DCT/DCU | 1 | 02_watchdog | A held ARM button cannot rearm after a watchdog clear; power-up reset supplied by ENOUT
SARM | Physical ARM NO | 1 | 02_watchdog
RARM | 10k | 1 | 02_watchdog
RARM_PD | 100k | 1 | 02_watchdog
CARM | 100nF | 1 | 02_watchdog
USCH | SN74LVC1G17 | 1 | 02_watchdog
UAND | SN74LVC1G08 | 1 | 02_watchdog
UINV | SN74LVC1G04 | 1 | 02_watchdog
UGATE | SN74AHCT1G125 | 1 | 02_watchdog | TTL input accepts 3.3V; 5V gate drive makes FQP30N06L Rds specification applicable
RSA | 10k | 1 | 02_watchdog
RHB | 10k | 1 | 02_watchdog
RSLEEP | 10k | 1 | 02_watchdog
RHW | 100k | 1 | 02_watchdog
CWD | 100nF at IC | 1 | 02_watchdog
CFF | 100nF at IC | 1 | 02_watchdog
CSCH | 100nF at IC | 1 | 02_watchdog
CAND | 100nF at IC | 1 | 02_watchdog
CINV | 100nF at IC | 1 | 02_watchdog
CGATE | 100nF at IC | 1 | 02_watchdog
JPI | Raspberry Pi5 40-pin header | 1 | 03_io | Number is physical header pin; BCM is in pin name. Omitted pins not connected; power arrives via USB-C.
UADC | MCP3008 / DIP-16 | 1 | 03_io
UDIR | MCP23S17 / DIP-28 | 1 | 03_io | Remaining GPIO are unused inputs; enable pull-ups in software. INT pins unused.
RDIR | 10k | 1 | 03_io
UPWM | PCA9685 / TSSOP28 | 1 | 03_io | Internal oscillator; nominal1017Hz. LED4..15 not connected. No 20kHz claim.
ROE | 10k | 1 | 03_io
UENC0 | LS7366R / DIP14 | 1 | 03_io
JENC0 | Encoder / 3.3V quadrature | 1 | 03_io | 2048 effective counts/wheel revolution required by current Java constants; otherwise change and recalibrate.
UENC1 | LS7366R / DIP14 | 1 | 03_io
JENC1 | Encoder / 3.3V quadrature | 1 | 03_io | 2048 effective counts/wheel revolution required by current Java constants; otherwise change and recalibrate.
X1 | 1MHz CMOS oscillator / 3.3V | 1 | 03_io | Oscillator footprint/package pinout to be selected; interface numbers only.
CADC | 100nF at IC | 1 | 03_io
CDIR | 100nF at IC | 1 | 03_io
CPWM | 100nF at IC | 1 | 03_io
CENC0 | 100nF at IC | 1 | 03_io
CENC1 | 100nF at IC | 1 | 03_io
CX | 100nF at IC | 1 | 03_io
SES | NC healthy; dedicated isolated auxiliary pole | 1 | 04_sensors
RSES | 10k external pullup | 1 | 04_sensors
SBU | NC healthy; separate contact from CLEAR chain | 1 | 04_sensors
RSBU | 10k external pullup | 1 | 04_sensors
SCL | NC healthy from validated cliff detector | 1 | 04_sensors
RSCL | 10k external pullup | 1 | 04_sensors
SGU | NC healthy | 1 | 04_sensors
RSGU | 10k external pullup | 1 | 04_sensors
SFU | NC healthy; opens when hopper full | 1 | 04_sensors
RSFU | 10k external pullup | 1 | 04_sensors
JB0 | Beam receiver / open collector | 1 | 04_sensors | LOW=beam broken; 3.3V-safe open collector, not a 24V push-pull output
RB0 | 10k | 1 | 04_sensors
JB1 | Beam receiver / open collector | 1 | 04_sensors | LOW=beam broken; 3.3V-safe open collector, not a 24V push-pull output
RB1 | 10k | 1 | 04_sensors
RF | 10k external pullup | 1 | 04_sensors
RK | 10k external pullup | 1 | 04_sensors
JRANGE | Calibrated analog obstacle sensor | 1 | 04_sensors | Output must remain0..3.3V with external conditioning. Exact sensor/range curve is a commissioning decision; config rejects missing table.
FM0 | 4A DC | 1 | 05_motor_left
UM0 | DRV8874 HTSSOP16-PAD | 1 | 05_motor_left | PMODE=0 PH/EN. IMODE=0 current regulation; verify layout/thermal ratings, 6A peak is NOT continuous.
M0 | 24V brushed gearmotor | 1 | 05_motor_left | 30rpm >=4Nm loaded
CCP0 | 22nF / 50V | 1 | 05_motor_left
CVCP0 | 100nF /16V | 1 | 05_motor_left | VCP capacitor is to VM, NOT ground
CVM0 | 100nF /50V | 1 | 05_motor_left
CB0 | 470uF /50V | 1 | 05_motor_left
RIP0 | 1.5k /1% | 1 | 05_motor_left
RFLT0 | 10k | 1 | 05_motor_left
CFLT0 | 100nF | 1 | 05_motor_left | Filtered current reflects duty/recirculation; calibrate software thresholds
RVT0 | 6.19k /1% | 1 | 05_motor_left
RVB0 | 10k /1% | 1 | 05_motor_left
REN0 | 47k | 1 | 05_motor_left
RPH0 | 47k | 1 | 05_motor_left
CM0 | 10nF /50V motor suppression | 1 | 05_motor_left | Validate suppression with driver current/EMI; twist motor pair
FM1 | 4A DC | 1 | 06_motor_right
UM1 | DRV8874 HTSSOP16-PAD | 1 | 06_motor_right | PMODE=0 PH/EN. IMODE=0 current regulation; verify layout/thermal ratings, 6A peak is NOT continuous.
M1 | 24V brushed gearmotor | 1 | 06_motor_right | 30rpm >=4Nm loaded
CCP1 | 22nF / 50V | 1 | 06_motor_right
CVCP1 | 100nF /16V | 1 | 06_motor_right | VCP capacitor is to VM, NOT ground
CVM1 | 100nF /50V | 1 | 06_motor_right
CB1 | 470uF /50V | 1 | 06_motor_right
RIP1 | 1.5k /1% | 1 | 06_motor_right
RFLT1 | 10k | 1 | 06_motor_right
CFLT1 | 100nF | 1 | 06_motor_right | Filtered current reflects duty/recirculation; calibrate software thresholds
RVT1 | 6.19k /1% | 1 | 06_motor_right
RVB1 | 10k /1% | 1 | 06_motor_right
REN1 | 47k | 1 | 06_motor_right
RPH1 | 47k | 1 | 06_motor_right
CM1 | 10nF /50V motor suppression | 1 | 06_motor_right | Validate suppression with driver current/EMI; twist motor pair
FM2 | 3A DC | 1 | 07_motor_brush
UM2 | DRV8874 HTSSOP16-PAD | 1 | 07_motor_brush | PMODE=0 PH/EN. IMODE=0 current regulation; verify layout/thermal ratings, 6A peak is NOT continuous.
M2 | 24V brushed gearmotor | 1 | 07_motor_brush | 120rpm brush
CCP2 | 22nF / 50V | 1 | 07_motor_brush
CVCP2 | 100nF /16V | 1 | 07_motor_brush | VCP capacitor is to VM, NOT ground
CVM2 | 100nF /50V | 1 | 07_motor_brush
CB2 | 470uF /50V | 1 | 07_motor_brush
RIP2 | 1.5k /1% | 1 | 07_motor_brush
RFLT2 | 10k | 1 | 07_motor_brush
CFLT2 | 100nF | 1 | 07_motor_brush | Filtered current reflects duty/recirculation; calibrate software thresholds
RVT2 | 14.3k /1% | 1 | 07_motor_brush
RVB2 | 10k /1% | 1 | 07_motor_brush
REN2 | 47k | 1 | 07_motor_brush
RPH2 | 47k | 1 | 07_motor_brush
CM2 | 10nF /50V motor suppression | 1 | 07_motor_brush | Validate suppression with driver current/EMI; twist motor pair
FM3 | 3A DC | 1 | 08_motor_belt
UM3 | DRV8874 HTSSOP16-PAD | 1 | 08_motor_belt | PMODE=0 PH/EN. IMODE=0 current regulation; verify layout/thermal ratings, 6A peak is NOT continuous.
M3 | 24V brushed gearmotor | 1 | 08_motor_belt | 45..60rpm conveyor
CCP3 | 22nF / 50V | 1 | 08_motor_belt
CVCP3 | 100nF /16V | 1 | 08_motor_belt | VCP capacitor is to VM, NOT ground
CVM3 | 100nF /50V | 1 | 08_motor_belt
CB3 | 470uF /50V | 1 | 08_motor_belt
RIP3 | 1.5k /1% | 1 | 08_motor_belt
RFLT3 | 10k | 1 | 08_motor_belt
CFLT3 | 100nF | 1 | 08_motor_belt | Filtered current reflects duty/recirculation; calibrate software thresholds
RVT3 | 14.3k /1% | 1 | 08_motor_belt
RVB3 | 10k /1% | 1 | 08_motor_belt
REN3 | 47k | 1 | 08_motor_belt
RPH3 | 47k | 1 | 08_motor_belt
CM3 | 10nF /50V motor suppression | 1 | 08_motor_belt | Validate suppression with driver current/EMI; twist motor pair

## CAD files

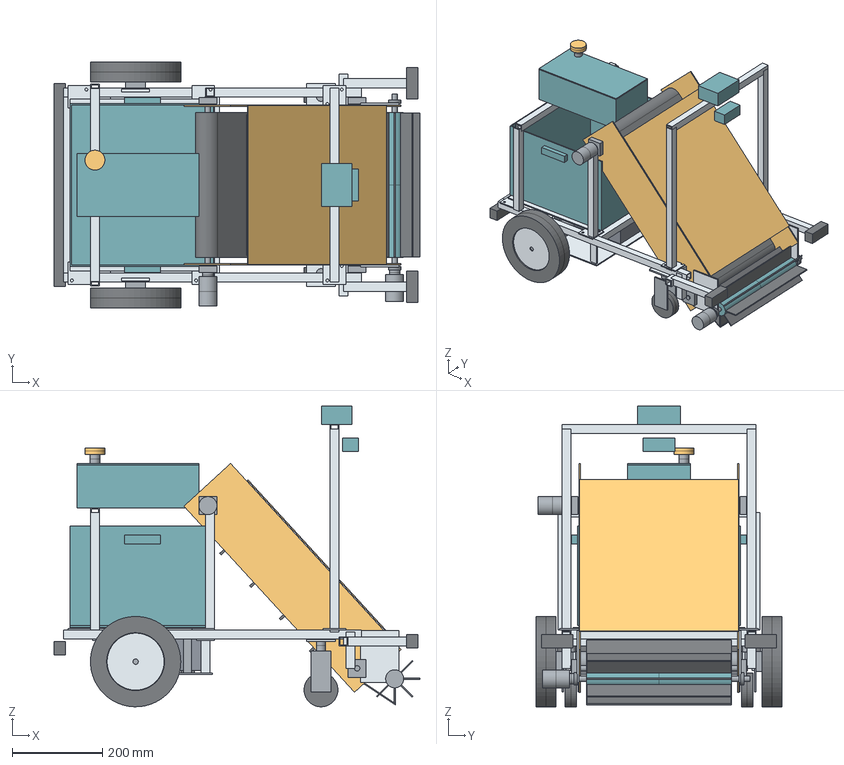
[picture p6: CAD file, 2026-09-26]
cad/step/UBOR_JAVA_R01_assembly.step
809.5 x 545.0 x 665.0 mm
frame_side_-1
frame_side_+1
cross_member_-340
cross_member_-15
cross_member_270
bin_support_deck
gusset_-315_-195
gusset_-315_195
gusset_-40_-195
gusset_-40_195
gusset_250_-195
gusset_250_195
tyre_-1
hub_-1
wheel_shaft_-1
drive_mount_-1
drive_motor_envelope_-1
wheel_bearing_block_-1
tyre_+1
hub_+1
wheel_shaft_+1
drive_mount_+1
drive_motor_envelope_+1
wheel_bearing_block_+1
caster_tyre_-1
caster_fork_-1_-1
caster_fork_-1_+1
caster_pivot_-1
caster_mount_-1
caster_tyre_+1
caster_fork_+1_-1
caster_fork_+1_+1
caster_pivot_+1
caster_mount_+1
bin_slide_-1
bin_slide_+1
removable_bin
bin_handle_-1
bin_handle_+1
battery_8S_LFP_envelope
battery_strap_-1
battery_strap_+1
battery_tray
battery_hanger_-265_-1
battery_hanger_flange_-265_-1
battery_hanger_-265_+1
battery_hanger_flange_-265_+1
battery_hanger_-35_-1
battery_hanger_flange_-35_-1
battery_hanger_-35_+1
battery_hanger_flange_-35_+1
battery_pad_-225
battery_strap_leg_-225_-1
battery_strap_leg_-225_+1
battery_pad_-75
battery_strap_leg_-75_-1
battery_strap_leg_-75_+1
endless_belt
lower_roller
lower_shaft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

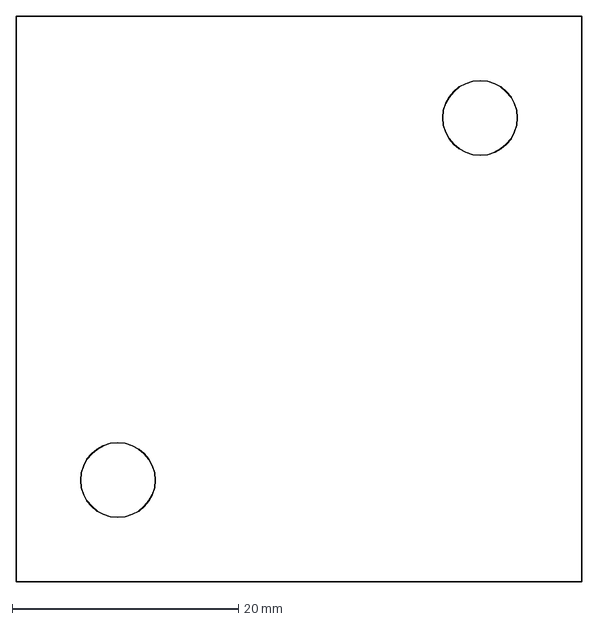
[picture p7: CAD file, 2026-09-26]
cad/drawings/gusset_cut_50x50.dxf
50.0 x 50.0 mm

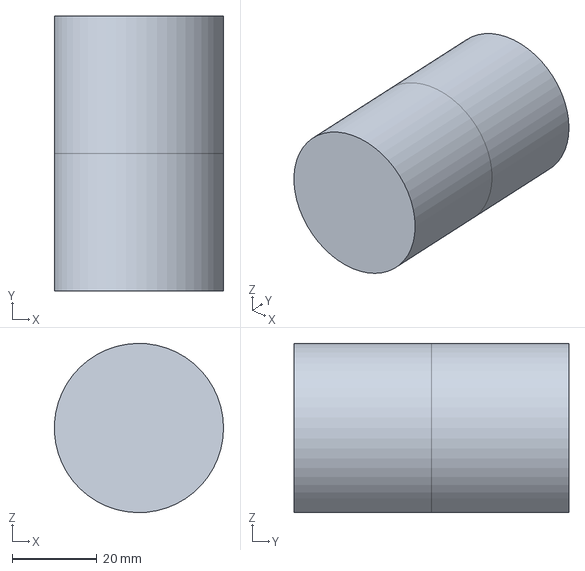
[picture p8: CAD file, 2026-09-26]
cad/parts/conveyor_motor_envelope.step
40.0 x 65.0 x 40.0 mm

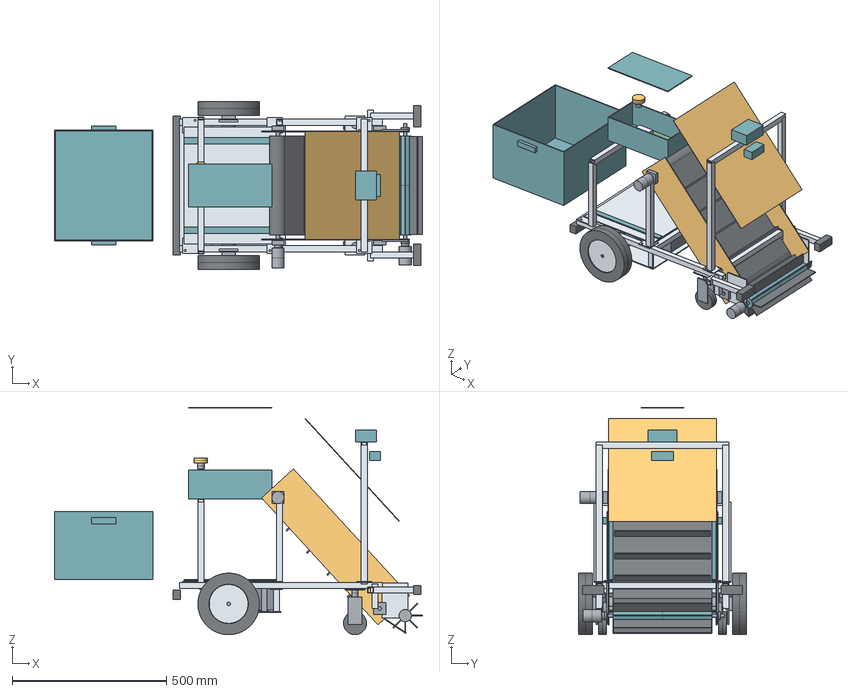
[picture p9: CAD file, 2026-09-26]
cad/step/UBOR_JAVA_R01_service.step
1194.0 x 545.0 x 738.0 mm
frame_side_-1
frame_side_+1
cross_member_-340
cross_member_-15
cross_member_270
bin_support_deck
gusset_-315_-195
gusset_-315_195
gusset_-40_-195
gusset_-40_195
gusset_250_-195
gusset_250_195
tyre_-1
hub_-1
wheel_shaft_-1
drive_mount_-1
drive_motor_envelope_-1
wheel_bearing_block_-1
tyre_+1
hub_+1
wheel_shaft_+1
drive_mount_+1
drive_motor_envelope_+1
wheel_bearing_block_+1
caster_tyre_-1
caster_fork_-1_-1
caster_fork_-1_+1
caster_pivot_-1
caster_mount_-1
caster_tyre_+1
caster_fork_+1_-1
caster_fork_+1_+1
caster_pivot_+1
caster_mount_+1
bin_slide_-1
bin_slide_+1
removable_bin
bin_handle_-1
bin_handle_+1
battery_8S_LFP_envelope
battery_strap_-1
battery_strap_+1
battery_tray
battery_hanger_-265_-1
battery_hanger_flange_-265_-1
battery_hanger_-265_+1
battery_hanger_flange_-265_+1
battery_hanger_-35_-1
battery_hanger_flange_-35_-1
battery_hanger_-35_+1
battery_hanger_flange_-35_+1
battery_pad_-225
battery_strap_leg_-225_-1
battery_strap_leg_-225_+1
battery_pad_-75
battery_strap_leg_-75_-1
battery_strap_leg_-75_+1
endless_belt
lower_roller
lower_shaft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

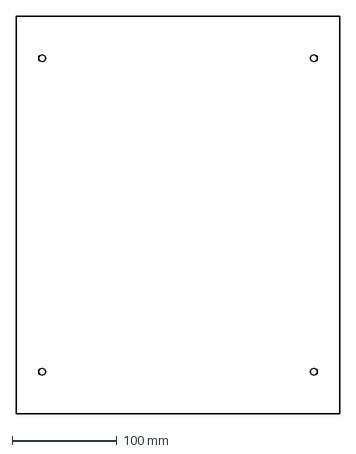
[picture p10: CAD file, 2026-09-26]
cad/drawings/bin_support_deck_cut_310x380.dxf
310.0 x 380.0 mm

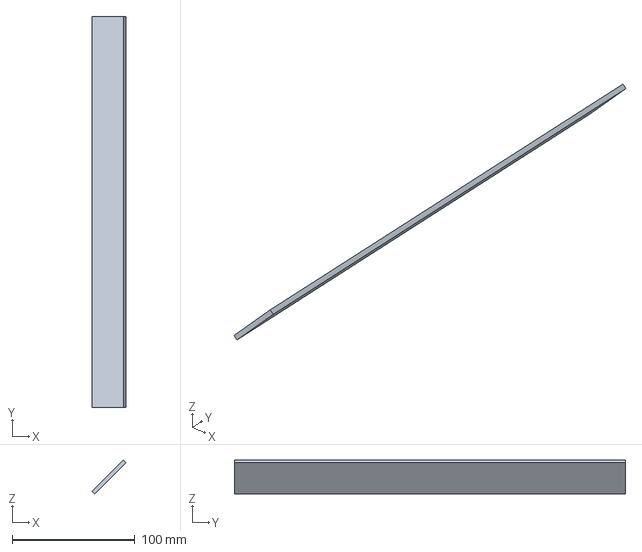
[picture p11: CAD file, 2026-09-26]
cad/parts/brush_fin_7.step
27.6 x 318.0 x 27.6 mm

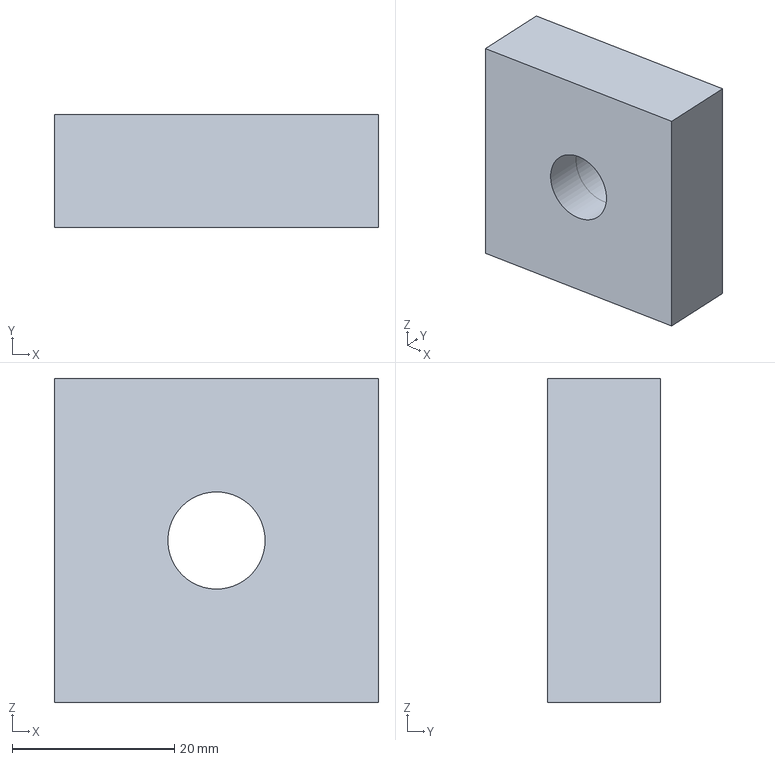
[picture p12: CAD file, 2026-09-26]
cad/parts/lower_bearing_+1.step
40.0 x 14.0 x 40.0 mm

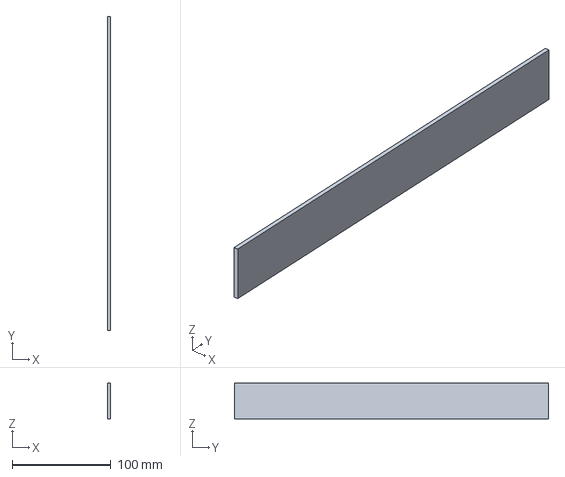
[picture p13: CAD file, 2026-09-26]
cad/parts/brush_fin_2.step
3.00 x 318.0 x 36.0 mm

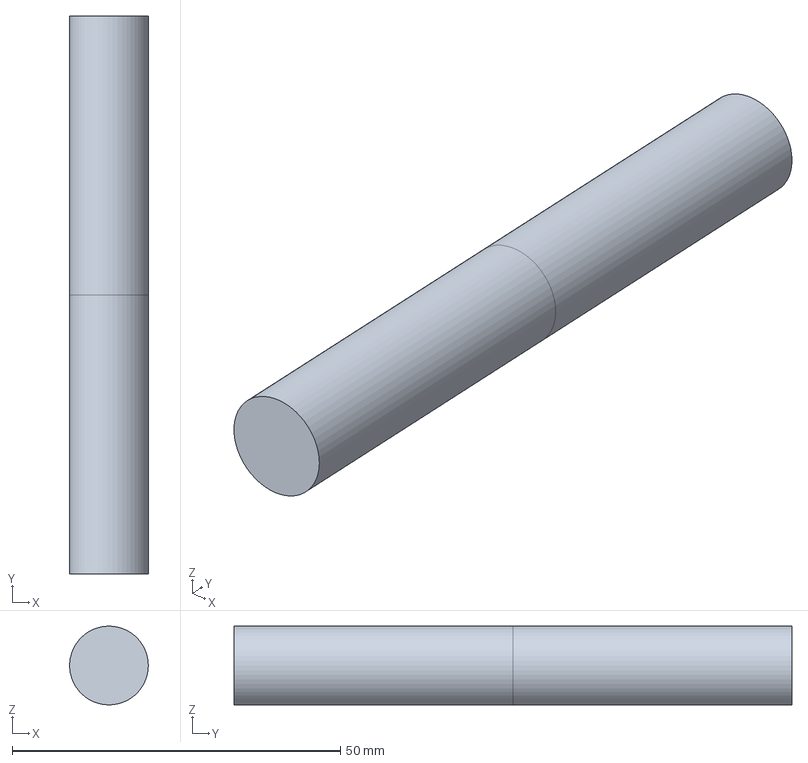
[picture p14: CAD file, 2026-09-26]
cad/parts/wheel_shaft_+1.step
12.0 x 85.0 x 12.0 mm

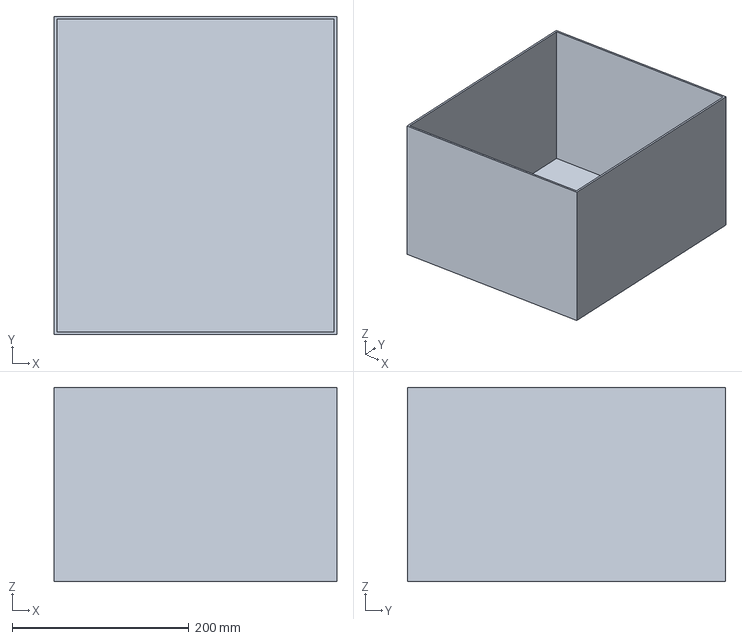
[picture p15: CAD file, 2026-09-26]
cad/parts/removable_bin.step
320.0 x 360.0 x 220.0 mm

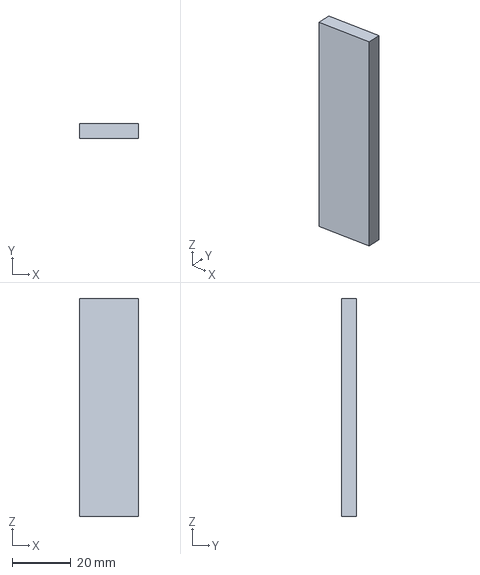
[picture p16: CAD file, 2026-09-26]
cad/parts/battery_hanger_-265_+1.step
20.0 x 5.00 x 74.0 mm

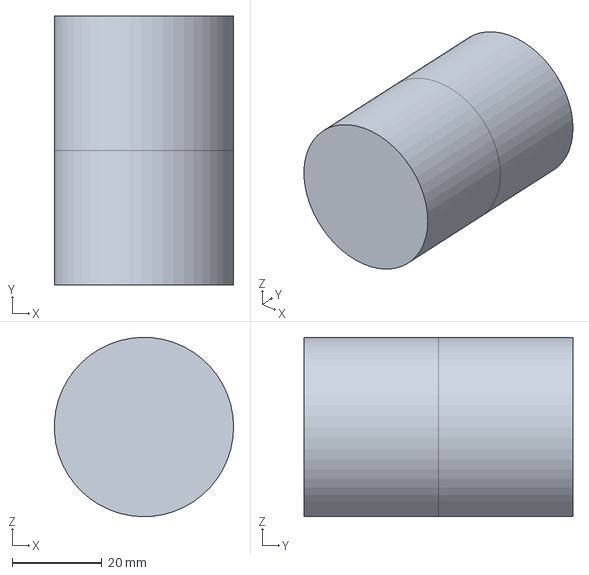
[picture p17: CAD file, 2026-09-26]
cad/parts/brush_motor_envelope.step
40.0 x 60.0 x 40.0 mm

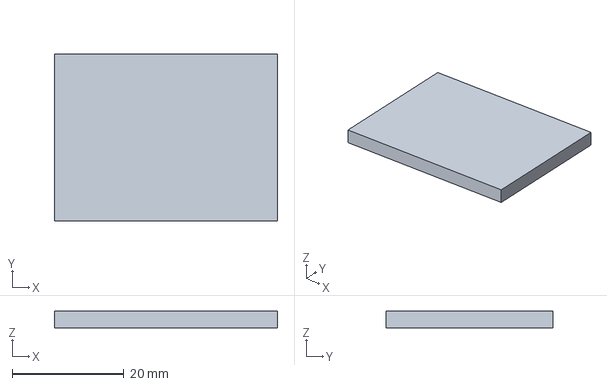
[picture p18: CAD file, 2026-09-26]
cad/parts/battery_hanger_flange_-265_+1.step
40.0 x 30.0 x 3.00 mm

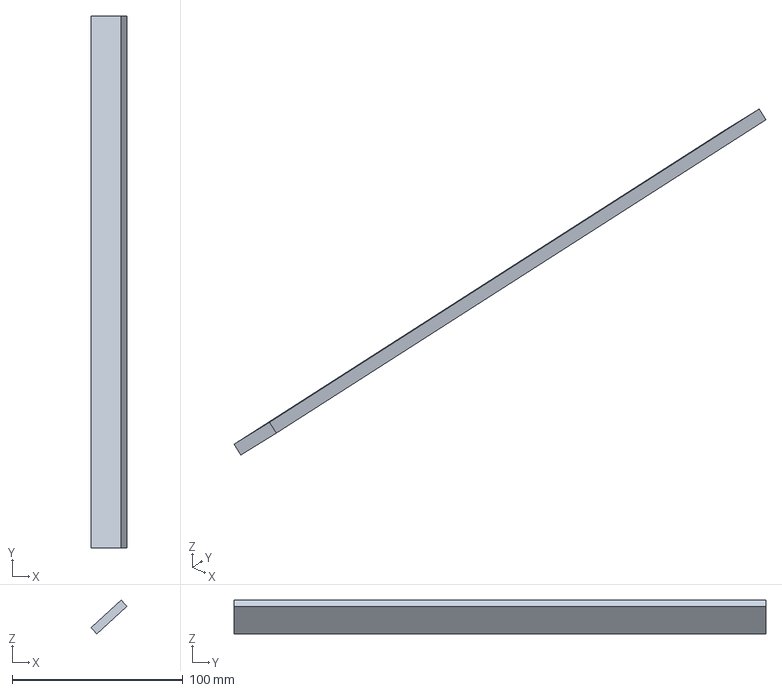
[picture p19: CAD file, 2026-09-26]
cad/parts/cleat_2_1.step
21.1 x 312.0 x 19.9 mm

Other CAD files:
cad/step/UBOR_JAVA_R01.stl
cad/parts/battery_hanger_-35_+1.step
cad/parts/UVC_camera_envelope.step
cad/parts/brush_fin_5.step
cad/parts/battery_8S_LFP_envelope.step
cad/parts/battery_hanger_-265_-1.step
cad/parts/battery_hanger_-35_-1.step
cad/parts/battery_hanger_flange_-265_-1.step
cad/parts/battery_hanger_flange_-35_+1.step
cad/parts/battery_hanger_flange_-35_-1.step
cad/parts/battery_pad_-225.step
cad/parts/battery_pad_-75.step
cad/parts/battery_strap_+1.step
cad/parts/battery_strap_-1.step
cad/parts/battery_strap_leg_-225_+1.step
cad/parts/battery_strap_leg_-225_-1.step
cad/parts/battery_strap_leg_-75_+1.step
cad/parts/battery_strap_leg_-75_-1.step
cad/parts/battery_tray.step
cad/parts/bin_handle_+1.step
cad/parts/bin_handle_-1.step
cad/parts/bin_slide_+1.step
cad/parts/bin_slide_-1.step
cad/parts/bin_support_deck.step
cad/parts/brush_bearing_+1.step
cad/parts/brush_bearing_-1.step
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

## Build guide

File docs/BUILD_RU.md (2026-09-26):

# R02: дополнение по сборке WPILib

Для новой физической модели: из `software` выполнить `mvn -Pwpilib clean verify`, затем `run-wpilib.cmd --desktop` (Windows) или `./run-wpilib.sh --desktop` (Linux). Нужны JDK 21, Maven 3.9+ и сетевой доступ к зависимостям. Этот маршрут в среде подготовки НЕ выполнен.

`software/dist/ubor-sim.jar` — действительно собранный старый backend LEGACY_FIRST_ORDER, НЕ WPILib. `build-offline` не компилирует WPILib. Полная новая инструкция — `README_RU.md` и `docs/25_WPILIB_R02.md`.

Исходный раздел ниже относится к R01. Архивные результаты перенесены в `verification/r01_archive/`. Генераторы R01 не создают новую главу WPILib; для неё предназначен `tools/render_wpilib_docs.py`.

---

# Воспроизводимая сборка комплекта

Готовые STEP, PDF и исполняемый симулятор уже находятся в архиве. Для просмотра этих файлов не нужно запускать генераторы.

## Java

Симулятор и пульт: JDK 21; Linux `software/build-offline.sh`, Windows `software/build-offline.ps1`. Сборка этих двух модулей не загружает сторонние зависимости.

Полный набор модулей: JDK 21, Maven, доступ к репозиторию зависимостей. Из каталога `software`: `mvn -Pfull clean install`, затем `bash assemble-full.sh`. Этот маршрут предусмотрен, но здесь не выполнялся. Не воспринимать наличие POM как доказательство совместимости нативного backend на Raspberry Pi. Начать целевую проверку с главы 19 книги и ML Preflight, не включая силовую часть.

## CAD и документы

Инструменты генерации работают на компьютере разработчика, не на роботе. Собственное бортовое ПО остаётся Java. Зафиксированные версии Python-пакетов находятся в `tools/requirements-cad-docs.txt`. Для CadQuery/VTK требуются совместимые нативные библиотеки и платформа; для PDF — системный пакет шрифтов DejaVu. Файлы шрифтов в архив не включены.

Из корня проекта, после установки необходимых зависимостей в отдельное окружение:

```sh
python cad/src/build_robot.py
python cad/src/render_cad.py
python tools/check_step.py
python tools/build_electronics.py
python tools/build_documents.py
```

`build_robot.py` создаёт геометрию, STEP деталей и сборок, BOM, расчётные параметры и ортогональные SVG. Рендер использует сохранённую CAD-сцену. `export_views.py` можно запускать отдельно для восстановления SVG из основного STEP. `build_electronics.py` создаёт граф соединений и KiCad-файлы; установленный KiCad этим скриптом не запускается. `build_documents.py` собирает книгу и PDF-комплекты из Markdown, CAD и графа соединений.

Исходная проверочная среда — Linux x86_64; сведения в `verification/r01_archive/environment.json`. Запуск этих генераторов на Windows или иной платформе здесь не проверялся. Экспорт CAD в STEP не переносит дерево параметрических операций CadQuery в SolidWorks: правки с полной историей нужно вносить в исходник, либо заново создавать операции в целевой CAD.

При изменении конфигурации, кода, схемы или геометрии нужно заново выполнить соответствующие проверки, обновить отчёт и контрольные суммы. Результаты этой ревизии автоматически на изменённый вариант не распространяются.

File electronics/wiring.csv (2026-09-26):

net | ref | pin | pin_name | sheet
ADC_BAT | RVTOP | 2 | 2 | 01_power
ADC_BAT | RVBOT | 1 | 1 | 01_power
ADC_BAT | CV | 1 | 1 | 01_power
ADC_BAT | UADC | 1 | CH0 | 03_io
ARM_BUTTON | SARM | 2 | 2 | 02_watchdog
ARM_BUTTON | RARM | 1 | 1 | 02_watchdog
ARM_EDGE | UFF | 1 | CLK | 02_watchdog
ARM_EDGE | USCH | 4 | Y | 02_watchdog
ARM_RC | RARM | 2 | 2 | 02_watchdog
ARM_RC | RARM_PD | 1 | 1 | 02_watchdog
ARM_RC | CARM | 1 | 1 | 02_watchdog
ARM_RC | USCH | 2 | A | 02_watchdog
BAT_FUSED | F1 | 2 | 2 | 01_power
BAT_FUSED | S0 | 1 | 1 | 01_power
BAT_RAW | BT1 | 1 | PACK+ | 01_power
BAT_RAW | F1 | 1 | 1 | 01_power
BAT_SW | S0 | 2 | 2 | 01_power
BAT_SW | F2 | 1 | 1 | 01_power
BAT_SW | K1 | 1 | MAIN_IN | 01_power
BAT_SW | S1B | 1 | 1 | 01_power
BAT_SW | SPRE | 1 | 1 | 01_power
BAT_SW | RVTOP | 1 | 1 | 01_power
BUCK_IN | F2 | 2 | 2 | 01_power
BUCK_IN | PS1 | 1 | IN+ | 01_power
BUMPER_SENSE | JPI | 18 | BCM24 | 03_io
BUMPER_SENSE | SBU | 1 | 1 | 04_sensors
BUMPER_SENSE | RSBU | 2 | 2 | 04_sensors
CLEAR_N | S5A | 2 | 2 | 02_watchdog
CLEAR_N | RCLR | 1 | 1 | 02_watchdog
CLEAR_N | UFF | 6 | nCLR | 02_watchdog
CLIFF_SENSE | JPI | 22 | BCM25 | 03_io
CLIFF_SENSE | SCL | 1 | 1 | 04_sensors
CLIFF_SENSE | RSCL | 2 | 2 | 04_sensors
COIL_LOW | K1 | 4 | COIL- | 01_power
COIL_LOW | Q1 | 2 | D | 01_power
COIL_LOW | D1 | 2 | A | 01_power
COIL_PLUS | K1 | 3 | COIL+ | 01_power
COIL_PLUS | S1B | 2 | 2 | 01_power
COIL_PLUS | D1 | 1 | K | 01_power
CUR0 | UADC | 2 | CH1 | 03_io
CUR0 | RFLT0 | 2 | 2 | 05_motor_left
CUR0 | CFLT0 | 1 | 1 | 05_motor_left
CUR1 | UADC | 3 | CH2 | 03_io
CUR1 | RFLT1 | 2 | 2 | 06_motor_right
CUR1 | CFLT1 | 1 | 1 | 06_motor_right
CUR2 | UADC | 4 | CH3 | 03_io
CUR2 | RFLT2 | 2 | 2 | 07_motor_brush
CUR2 | CFLT2 | 1 | 1 | 07_motor_brush
CUR3 | UADC | 5 | CH4 | 03_io
CUR3 | RFLT3 | 2 | 2 | 08_motor_belt
CUR3 | CFLT3 | 1 | 1 | 08_motor_belt
CWD_SET | UWD | 2 | CWD | 02_watchdog
CWD_SET | RCWD | 2 | 2 | 02_watchdog
DIR0 | UDIR | 21 | GPA0 | 03_io
DIR0 | UM0 | 2 | PH | 05_motor_left
DIR0 | RPH0 | 1 | 1 | 05_motor_left
DIR1 | UDIR | 22 | GPA1 | 03_io
DIR1 | UM1 | 2 | PH | 06_motor_right
DIR1 | RPH1 | 1 | 1 | 06_motor_right
DIR2 | UDIR | 23 | GPA2 | 03_io
DIR2 | UM2 | 2 | PH | 07_motor_brush
DIR2 | RPH2 | 1 | 1 | 07_motor_brush
DIR3 | UDIR | 24 | GPA3 | 03_io
DIR3 | UM3 | 2 | PH | 08_motor_belt
DIR3 | RPH3 | 1 | 1 | 08_motor_belt
DIR_RST | UDIR | 18 | nRESET | 03_io
DIR_RST | RDIR | 2 | 2 | 03_io
DROP_BEAM | JPI | 33 | BCM13 | 03_io
DROP_BEAM | JB1 | 2 | OC_3V3 | 04_sensors
DROP_BEAM | RB1 | 2 | 2 | 04_sensors
DRV_FAULT_N | JPI | 36 | BCM16 | 03_io
DRV_FAULT_N | RF | 2 | 2 | 04_sensors
DRV_FAULT_N | UM0 | 4 | nFAULT | 05_motor_left
DRV_FAULT_N | UM1 | 4 | nFAULT | 06_motor_right
DRV_FAULT_N | UM2 | 4 | nFAULT | 07_motor_brush
DRV_FAULT_N | UM3 | 4 | nFAULT | 08_motor_belt
ENC0A | UENC0 | 12 | A | 03_io
ENC0A | JENC0 | 2 | A | 03_io
ENC0B | UENC0 | 11 | B | 03_io
ENC0B | JENC0 | 3 | B | 03_io
ENC1A | UENC1 | 12 | A | 03_io
ENC1A | JENC1 | 2 | A | 03_io
ENC1B | UENC1 | 11 | B | 03_io
ENC1B | JENC1 | 3 | B | 03_io
ENC_CLK | UENC0 | 2 | fCKi | 03_io
ENC_CLK | UENC1 | 2 | fCKi | 03_io
ENC_CLK | X1 | 3 | OUT | 03_io
ESTOP_SENSE | JPI | 16 | BCM23 | 03_io
ESTOP_SENSE | SES | 1 | 1 | 04_sensors
ESTOP_SENSE | RSES | 2 | 2 | 04_sensors
FULL_SENSE | JPI | 31 | BCM6 | 03_io
FULL_SENSE | SFU | 1 | 1 | 04_sensors
FULL_SENSE | RSFU | 2 | 2 | 04_sensors
GND | BT1 | 2 | PACK- | 01_power
GND | PS1 | 2 | IN- | 01_power
GND | PS1 | 4 | OUT- | 01_power
GND | JUSB1 | 2 | GND | 01_power
GND | K1 | 6 | AUX_COM | 01_power
GND | Q1 | 3 | S | 01_power
GND | RGS1 | 2 | 2 | 01_power
GND | CBULK | 2 | 2 | 01_power
GND | RBLEED | 2 | 2 | 01_power
GND | RVBOT | 2 | 2 | 01_power
GND | CV | 2 | 2 | 01_power
GND | UWD | 4 | GND | 02_watchdog
GND | UWD | 9 | PAD | 02_watchdog
GND | RWD_PD | 2 | 2 | 02_watchdog
GND | RCLR | 2 | 2 | 02_watchdog
GND | UFF | 4 | GND | 02_watchdog
GND | RARM_PD | 2 | 2 | 02_watchdog
GND | CARM | 2 | 2 | 02_watchdog
GND | USCH | 3 | GND | 02_watchdog
GND | UAND | 3 | GND | 02_watchdog
GND | UINV | 3 | GND | 02_watchdog
GND | UGATE | 1 | nOE | 02_watchdog
GND | UGATE | 3 | GND | 02_watchdog
GND | RSA | 2 | 2 | 02_watchdog
GND | RHB | 2 | 2 | 02_watchdog
GND | RSLEEP | 2 | 2 | 02_watchdog
GND | RHW | 2 | 2 | 02_watchdog
GND | CWD | 2 | 2 | 02_watchdog
GND | CFF | 2 | 2 | 02_watchdog
GND | CSCH | 2 | 2 | 02_watchdog
GND | CAND | 2 | 2 | 02_watchdog
GND | CINV | 2 | 2 | 02_watchdog
GND | CGATE | 2 | 2 | 02_watchdog
GND | JPI | 6 | GND | 03_io
GND | UADC | 7 | CH6 | 03_io
GND | UADC | 8 | CH7 | 03_io
GND | UADC | 9 | DGND | 03_io
GND | UADC | 14 | AGND | 03_io
GND | UDIR | 10 | VSS | 03_io
GND | UDIR | 15 | A0 | 03_io
GND | UDIR | 16 | A1 | 03_io
GND | UDIR | 17 | A2 | 03_io
GND | UPWM | 1 | A0 | 03_io
GND | UPWM | 2 | A1 | 03_io
GND | UPWM | 3 | A2 | 03_io
GND | UPWM | 4 | A3 | 03_io
GND | UPWM | 5 | A4 | 03_io
GND | UPWM | 14 | VSS | 03_io
GND | UPWM | 24 | A5 | 03_io
GND | UPWM | 27 | EXTCLK | 03_io
GND | UENC0 | 3 | VSS | 03_io
GND | JENC0 | 4 | GND | 03_io
GND | UENC1 | 3 | VSS | 03_io
GND | JENC1 | 4 | GND | 03_io
GND | X1 | 2 | GND | 03_io
GND | CADC | 2 | 2 | 03_io
GND | CDIR | 2 | 2 | 03_io
GND | CPWM | 2 | 2 | 03_io
GND | CENC0 | 2 | 2 | 03_io
GND | CENC1 | 2 | 2 | 03_io
GND | CX | 2 | 2 | 03_io
GND | SES | 2 | 2 | 04_sensors
GND | SBU | 2 | 2 | 04_sensors
GND | SCL | 2 | 2 | 04_sensors
GND | SGU | 2 | 2 | 04_sensors
GND | SFU | 2 | 2 | 04_sensors
GND | JB0 | 3 | GND | 04_sensors
GND | JB1 | 3 | GND | 04_sensors
GND | JRANGE | 3 | GND | 04_sensors
GND | UM0 | 7 | IMODE | 05_motor_left
GND | UM0 | 9 | PGND | 05_motor_left
GND | UM0 | 15 | GND | 05_motor_left
GND | UM0 | 16 | PMODE | 05_motor_left
GND | UM0 | 17 | PAD | 05_motor_left
GND | CVM0 | 2 | 2 | 05_motor_left
GND | CB0 | 2 | 2 | 05_motor_left
GND | RIP0 | 2 | 2 | 05_motor_left
GND | CFLT0 | 2 | 2 | 05_motor_left
GND | RVB0 | 2 | 2 | 05_motor_left
GND | REN0 | 2 | 2 | 05_motor_left
GND | RPH0 | 2 | 2 | 05_motor_left
GND | UM1 | 7 | IMODE | 06_motor_right
GND | UM1 | 9 | PGND | 06_motor_right
GND | UM1 | 15 | GND | 06_motor_right
GND | UM1 | 16 | PMODE | 06_motor_right
GND | UM1 | 17 | PAD | 06_motor_right
GND | CVM1 | 2 | 2 | 06_motor_right
GND | CB1 | 2 | 2 | 06_motor_right
GND | RIP1 | 2 | 2 | 06_motor_right
GND | CFLT1 | 2 | 2 | 06_motor_right
GND | RVB1 | 2 | 2 | 06_motor_right
GND | REN1 | 2 | 2 | 06_motor_right
GND | RPH1 | 2 | 2 | 06_motor_right
GND | UM2 | 7 | IMODE | 07_motor_brush
GND | UM2 | 9 | PGND | 07_motor_brush
GND | UM2 | 15 | GND | 07_motor_brush
GND | UM2 | 16 | PMODE | 07_motor_brush
GND | UM2 | 17 | PAD | 07_motor_brush
GND | CVM2 | 2 | 2 | 07_motor_brush
GND | CB2 | 2 | 2 | 07_motor_brush
GND | RIP2 | 2 | 2 | 07_motor_brush
GND | CFLT2 | 2 | 2 | 07_motor_brush
GND | RVB2 | 2 | 2 | 07_motor_brush
GND | REN2 | 2 | 2 | 07_motor_brush
GND | RPH2 | 2 | 2 | 07_motor_brush
GND | UM3 | 7 | IMODE | 08_motor_belt
GND | UM3 | 9 | PGND | 08_motor_belt
GND | UM3 | 15 | GND | 08_motor_belt
GND | UM3 | 16 | PMODE | 08_motor_belt
GND | UM3 | 17 | PAD | 08_motor_belt
GND | CVM3 | 2 | 2 | 08_motor_belt
GND | CB3 | 2 | 2 | 08_motor_belt
GND | RIP3 | 2 | 2 | 08_motor_belt
GND | CFLT3 | 2 | 2 | 08_motor_belt
GND | RVB3 | 2 | 2 | 08_motor_belt
GND | REN3 | 2 | 2 | 08_motor_belt
GND | RPH3 | 2 | 2 | 08_motor_belt
GUARD_SENSE | JPI | 29 | BCM5 | 03_io
GUARD_SENSE | SGU | 1 | 1 | 04_sensors
GUARD_SENSE | RSGU | 2 | 2 | 04_sensors
HEARTBEAT | UWD | 6 | WDI | 02_watchdog
HEARTBEAT | RHB | 1 | 1 | 02_watchdog
HEARTBEAT | JPI | 15 | BCM22 | 03_io
HW_ENABLE | UFF | 5 | Q | 02_watchdog
HW_ENABLE | UAND | 2 | B | 02_watchdog
HW_ENABLE | UGATE | 2 | A | 02_watchdog
HW_ENABLE | RHW | 1 | 1 | 02_watchdog
I2C_SCL | JPI | 5 | BCM3 | 03_io
I2C_SCL | UPWM | 25 | SCL | 03_io
I2C_SDA | JPI | 3 | BCM2 | 03_io
I2C_SDA | UPWM | 26 | SDA | 03_io
INTAKE_BEAM | JPI | 32 | BCM12 | 03_io
INTAKE_BEAM | JB0 | 2 | OC_3V3 | 04_sensors
INTAKE_BEAM | RB0 | 2 | 2 | 04_sensors
K1_GATE | Q1 | 1 | G | 01_power
K1_GATE | RG1 | 2 | 2 | 01_power
K1_GATE | RGS1 | 1 | 1 | 01_power
K1_GATE_DRIVE | RG1 | 1 | 1 | 01_power
K1_GATE_DRIVE | UGATE | 4 | Y | 02_watchdog
K1_SENSE | K1 | 5 | AUX_NO | 01_power
K1_SENSE | JPI | 37 | BCM26 | 03_io
K1_SENSE | RK | 2 | 2 | 04_sensors
M0_CPH | UM0 | 13 | CPH | 05_motor_left
M0_CPH | CCP0 | 1 | 1 | 05_motor_left
M0_CPL | UM0 | 14 | CPL | 05_motor_left
M0_CPL | CCP0 | 2 | 2 | 05_motor_left
M0_IP | UM0 | 6 | IPROPI | 05_motor_left
M0_IP | RIP0 | 1 | 1 | 05_motor_left
M0_IP | RFLT0 | 1 | 1 | 05_motor_left
M0_OUT1 | UM0 | 8 | OUT1 | 05_motor_left
M0_OUT1 | M0 | 1 | + / forward | 05_motor_left
M0_OUT1 | CM0 | 1 | 1 | 05_motor_left
M0_OUT2 | UM0 | 10 | OUT2 | 05_motor_left
M0_OUT2 | M0 | 2 | - / reverse | 05_motor_left
M0_OUT2 | CM0 | 2 | 2 | 05_motor_left
M0_VCP | UM0 | 12 | VCP | 05_motor_left
M0_VCP | CVCP0 | 1 | 1 | 05_motor_left
M0_VM | FM0 | 2 | 2 | 05_motor_left
M0_VM | UM0 | 11 | VM | 05_motor_left
M0_VM | CVCP0 | 2 | 2 | 05_motor_left
M0_VM | CVM0 | 1 | 1 | 05_motor_left
M0_VM | CB0 | 1 | 1 | 05_motor_left
M0_VREF | UM0 | 5 | VREF | 05_motor_left
M0_VREF | RVT0 | 2 | 2 | 05_motor_left
M0_VREF | RVB0 | 1 | 1 | 05_motor_left
M1_CPH | UM1 | 13 | CPH | 06_motor_right
M1_CPH | CCP1 | 1 | 1 | 06_motor_right
M1_CPL | UM1 | 14 | CPL | 06_motor_right
M1_CPL | CCP1 | 2 | 2 | 06_motor_right
M1_IP | UM1 | 6 | IPROPI | 06_motor_right
M1_IP | RIP1 | 1 | 1 | 06_motor_right
M1_IP | RFLT1 | 1 | 1 | 06_motor_right
M1_OUT1 | UM1 | 8 | OUT1 | 06_motor_right
M1_OUT1 | M1 | 1 | + / forward | 06_motor_right
M1_OUT1 | CM1 | 1 | 1 | 06_motor_right
M1_OUT2 | UM1 | 10 | OUT2 | 06_motor_right
M1_OUT2 | M1 | 2 | - / reverse | 06_motor_right
M1_OUT2 | CM1 | 2 | 2 | 06_motor_right
M1_VCP | UM1 | 12 | VCP | 06_motor_right
M1_VCP | CVCP1 | 1 | 1 | 06_motor_right
M1_VM | FM1 | 2 | 2 | 06_motor_right
M1_VM | UM1 | 11 | VM | 06_motor_right
M1_VM | CVCP1 | 2 | 2 | 06_motor_right
M1_VM | CVM1 | 1 | 1 | 06_motor_right
M1_VM | CB1 | 1 | 1 | 06_motor_right
M1_VREF | UM1 | 5 | VREF | 06_motor_right
M1_VREF | RVT1 | 2 | 2 | 06_motor_right
M1_VREF | RVB1 | 1 | 1 | 06_motor_right
M2_CPH | UM2 | 13 | CPH | 07_motor_brush
M2_CPH | CCP2 | 1 | 1 | 07_motor_brush
M2_CPL | UM2 | 14 | CPL | 07_motor_brush
M2_CPL | CCP2 | 2 | 2 | 07_motor_brush
M2_IP | UM2 | 6 | IPROPI | 07_motor_brush
M2_IP | RIP2 | 1 | 1 | 07_motor_brush
M2_IP | RFLT2 | 1 | 1 | 07_motor_brush
M2_OUT1 | UM2 | 8 | OUT1 | 07_motor_brush
M2_OUT1 | M2 | 1 | + / forward | 07_motor_brush
M2_OUT1 | CM2 | 1 | 1 | 07_motor_brush
M2_OUT2 | UM2 | 10 | OUT2 | 07_motor_brush
M2_OUT2 | M2 | 2 | - / reverse | 07_motor_brush
M2_OUT2 | CM2 | 2 | 2 | 07_motor_brush
M2_VCP | UM2 | 12 | VCP | 07_motor_brush
M2_VCP | CVCP2 | 1 | 1 | 07_motor_brush
M2_VM | FM2 | 2 | 2 | 07_motor_brush
M2_VM | UM2 | 11 | VM | 07_motor_brush
M2_VM | CVCP2 | 2 | 2 | 07_motor_brush
M2_VM | CVM2 | 1 | 1 | 07_motor_brush
M2_VM | CB2 | 1 | 1 | 07_motor_brush
M2_VREF | UM2 | 5 | VREF | 07_motor_brush
M2_VREF | RVT2 | 2 | 2 | 07_motor_brush
M2_VREF | RVB2 | 1 | 1 | 07_motor_brush
M3_CPH | UM3 | 13 | CPH | 08_motor_belt
M3_CPH | CCP3 | 1 | 1 | 08_motor_belt
M3_CPL | UM3 | 14 | CPL | 08_motor_belt
M3_CPL | CCP3 | 2 | 2 | 08_motor_belt
M3_IP | UM3 | 6 | IPROPI | 08_motor_belt
M3_IP | RIP3 | 1 | 1 | 08_motor_belt
M3_IP | RFLT3 | 1 | 1 | 08_motor_belt
M3_OUT1 | UM3 | 8 | OUT1 | 08_motor_belt
M3_OUT1 | M3 | 1 | + / forward | 08_motor_belt
M3_OUT1 | CM3 | 1 | 1 | 08_motor_belt
M3_OUT2 | UM3 | 10 | OUT2 | 08_motor_belt
M3_OUT2 | M3 | 2 | - / reverse | 08_motor_belt
M3_OUT2 | CM3 | 2 | 2 | 08_motor_belt
M3_VCP | UM3 | 12 | VCP | 08_motor_belt
M3_VCP | CVCP3 | 1 | 1 | 08_motor_belt
M3_VM | FM3 | 2 | 2 | 08_motor_belt
M3_VM | UM3 | 11 | VM | 08_motor_belt
M3_VM | CVCP3 | 2 | 2 | 08_motor_belt
M3_VM | CVM3 | 1 | 1 | 08_motor_belt
M3_VM | CB3 | 1 | 1 | 08_motor_belt
M3_VREF | UM3 | 5 | VREF | 08_motor_belt
M3_VREF | RVT3 | 2 | 2 | 08_motor_belt
M3_VREF | RVB3 | 1 | 1 | 08_motor_belt
PRE_R | SPRE | 2 | 2 | 01_power
PRE_R | RPRE | 1 | 1 | 01_power
PWM0 | UPWM | 6 | LED0 | 03_io
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

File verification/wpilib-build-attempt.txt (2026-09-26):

Install Maven 3.9+ and Java 21, then rerun.

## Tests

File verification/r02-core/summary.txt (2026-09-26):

PASS 50 assertions
Java 21.0.11
Only dependency-free core/app; no Pi4J, DL4J, ARM, GPIO or camera execution.
fresh/current
fresh/future-rejected
fresh/expired
command/NaN
actuation/bounds
manual/valid
lease/expired
deadman/release
interlock/emergency
interlock/bumper
interlock/cliff
interlock/cover
interlock/full
interlock/permit
interlock/driver
interlock/voltage
interlock/obstacle
sensor/stale
fault/latches
fault/explicit-reset
deadline/trips
current/stall-latches
vision/missing-stops
vision/old-stops
vision/hazard-stops
vision/low-confidence
pickup/manual-speed-clamp
pickup/unknown-not-collected
pickup/auto-start
pickup/stop-chassis-after-intake
pickup/drop-confirmed
protocol/round-trip
protocol/replay-rejected
protocol/tampering-rejected
protocol/other-session
protocol/short-packet
SPI/ADC-decode
SPI/ADC-command
SPI/ADC-invalid-channel
PWM/channel-register
PWM/half-duty
PWM/full-off-bit
GPIO-expander/init-direction
PWM/no-ALL-register-write-after-channel-duty
encoder/signed-wrap
kinematics/differential
drive/immediate-disable
sim/watchdog-drops-permit
integration/oracle-collects-three
integration/hazard-left-behind

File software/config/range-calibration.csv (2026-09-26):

voltage | distance_m
# Enter at least four measured monotonic calibration points. No invented curve supplied.

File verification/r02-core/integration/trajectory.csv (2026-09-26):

t_s | x_m | y_m | heading_rad | mode | reason | v_m_s | w_rad_s | left_duty | right_duty | brush_duty | belt_duty | collected | battery_v | left_a | right_a | brush_a | belt_a | left_counts | right_counts | left_mps | right_mps
0.00 | 0.00000 | 0.00000 | 0.00000 | AUTO | MODEL_PROPOSAL | 0.1999 | 0.0666 | 0.0400 | 0.0400 | 0.0000 | 0.0000 | 0 | 25.60000 | 0.15000 | 0.15000 | 0.00000 | 0.00000 | 0 | 0 | 0.000000 | 0.000000
0.02 | 0.00003 | 0.00000 | 0.00000 | AUTO | MODEL_PROPOSAL | 0.1999 | 0.0666 | 0.0800 | 0.0800 | 0.0000 | 0.0000 | 0 | 25.60000 | 0.19000 | 0.19000 | 0.00000 | 0.00000 | 0 | 0 | 0.001728 | 0.001728
0.04 | 0.00011 | 0.00000 | 0.00000 | AUTO | MODEL_PROPOSAL | 0.1999 | 0.0666 | 0.1200 | 0.1200 | 0.0000 | 0.0000 | 0 | 25.60000 | 0.23000 | 0.23000 | 0.00000 | 0.00000 | 0 | 0 | 0.004998 | 0.004998
0.06 | 0.00028 | 0.00000 | 0.00000 | AUTO | MODEL_PROPOSAL | 0.1999 | 0.0667 | 0.1600 | 0.1600 | 0.0000 | 0.0000 | 0 | 25.60000 | 0.27000 | 0.27000 | 0.00000 | 0.00000 | 1 | 1 | 0.009644 | 0.009644
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

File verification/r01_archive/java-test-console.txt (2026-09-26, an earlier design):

PASS fresh/current
PASS fresh/future-rejected
PASS fresh/expired
PASS command/NaN
PASS actuation/bounds
PASS manual/valid
PASS lease/expired
PASS deadman/release
PASS interlock/emergency
PASS interlock/bumper
PASS interlock/cliff
PASS interlock/cover
PASS interlock/full
PASS interlock/permit
PASS interlock/driver
PASS interlock/voltage
PASS interlock/obstacle
PASS sensor/stale
PASS fault/latches
PASS fault/explicit-reset
PASS deadline/trips
PASS current/stall-latches
PASS vision/missing-stops
PASS vision/old-stops
PASS vision/hazard-stops
PASS vision/low-confidence
PASS pickup/manual-speed-clamp
PASS pickup/unknown-not-collected
PASS pickup/auto-start
PASS pickup/stop-chassis-after-intake
PASS pickup/drop-confirmed
PASS protocol/round-trip
PASS protocol/replay-rejected
PASS protocol/tampering-rejected
PASS protocol/other-session
PASS protocol/short-packet
PASS SPI/ADC-decode
PASS SPI/ADC-command
PASS SPI/ADC-invalid-channel
PASS PWM/channel-register
PASS PWM/half-duty
PASS PWM/full-off-bit
PASS GPIO-expander/init-direction
PASS PWM/no-ALL-register-write-after-channel-duty
PASS encoder/signed-wrap
PASS kinematics/differential
PASS drive/immediate-disable
PASS sim/watchdog-drops-permit
PASS integration/oracle-collects-three
PASS integration/hazard-left-behind
PASS 50 assertions

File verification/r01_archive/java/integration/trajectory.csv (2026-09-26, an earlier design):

t_s | x_m | y_m | heading_rad | mode | reason | v_m_s | w_rad_s | left_duty | right_duty | brush_duty | belt_duty | collected
0.00 | 0.00000 | 0.00000 | 0.00000 | AUTO | MODEL_PROPOSAL | 0.1999 | 0.0666 | 0.0400 | 0.0400 | 0.0000 | 0.0000 | 0
0.02 | 0.00003 | 0.00000 | 0.00000 | AUTO | MODEL_PROPOSAL | 0.1999 | 0.0666 | 0.0800 | 0.0800 | 0.0000 | 0.0000 | 0
0.04 | 0.00011 | 0.00000 | 0.00000 | AUTO | MODEL_PROPOSAL | 0.1999 | 0.0666 | 0.1200 | 0.1200 | 0.0000 | 0.0000 | 0
0.06 | 0.00028 | 0.00000 | 0.00000 | AUTO | MODEL_PROPOSAL | 0.1999 | 0.0667 | 0.1600 | 0.1600 | 0.0000 | 0.0000 | 0
0.08 | 0.00056 | 0.00000 | 0.00000 | AUTO | MODEL_PROPOSAL | 0.1999 | 0.0667 | 0.2000 | 0.2000 | 0.0000 | 0.0000 | 0
0.10 | 0.00098 | 0.00000 | 0.00000 | AUTO | MODEL_PROPOSAL | 0.1999 | 0.0667 | 0.2400 | 0.2400 | 0.0000 | 0.0000 | 0
0.12 | 0.00155 | 0.00000 | 0.00000 | AUTO | MODEL_PROPOSAL | 0.1999 | 0.0667 | 0.2800 | 0.2800 | 0.0000 | 0.0000 | 0
0.14 | 0.00229 | 0.00000 | 0.00000 | AUTO | MODEL_PROPOSAL | 0.1999 | 0.0667 | 0.3200 | 0.3200 | 0.0000 | 0.0000 | 0
0.16 | 0.00322 | 0.00000 | 0.00000 | AUTO | MODEL_PROPOSAL | 0.1999 | 0.0668 | 0.3600 | 0.3600 | 0.0000 | 0.0000 | 0
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

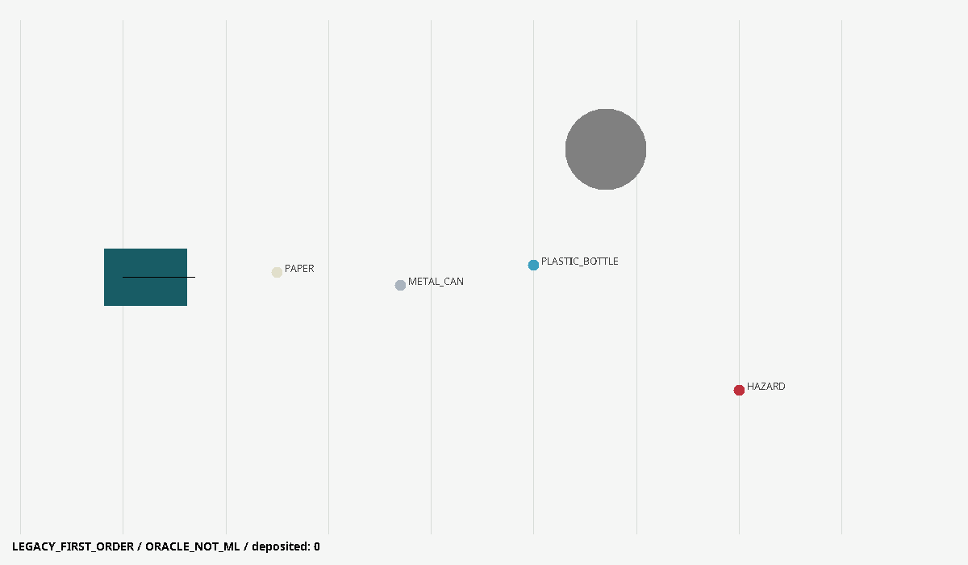
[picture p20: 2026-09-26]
verification/r02-core/integration/map_0000.png

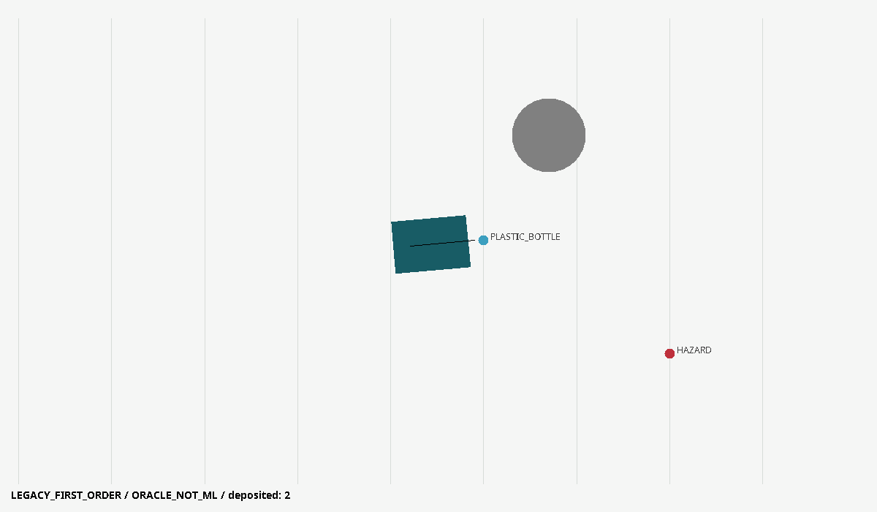
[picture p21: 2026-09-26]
verification/r02-core/integration/map_1500.png

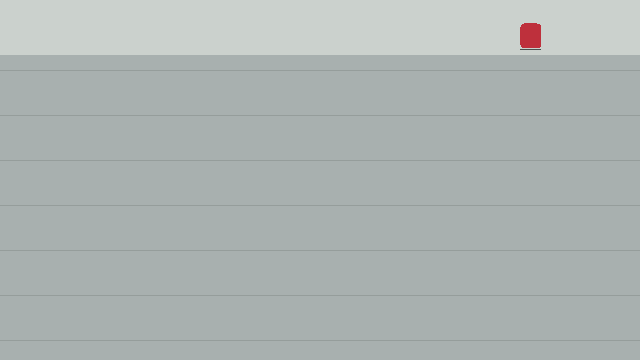
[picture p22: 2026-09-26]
verification/r02-core/integration/synthetic_camera.png

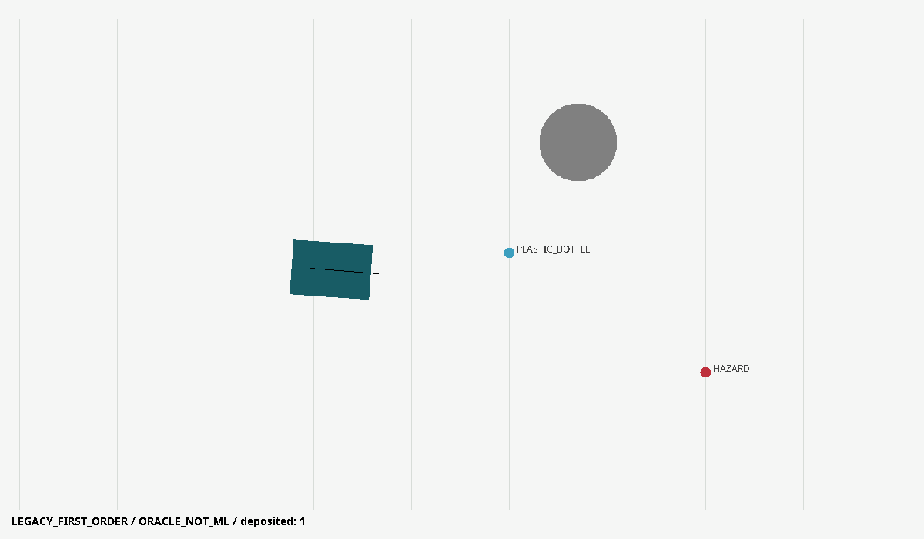
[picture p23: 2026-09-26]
verification/r02-core/integration/map_1000.png

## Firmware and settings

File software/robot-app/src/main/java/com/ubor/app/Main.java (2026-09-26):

package com.ubor.app;

import com.ubor.core.*;
import static com.ubor.core.Types.*;
import java.nio.file.*;
import java.net.*;
import java.util.concurrent.*;
import javax.swing.*;

public final class Main {
    private static byte[] key(){return ControlProtocol.keyFromEnvironment();}
    private static void waitForever()throws InterruptedException {new CountDownLatch(1).await();}
    public static void main(String[] args)throws Exception {
        if(args.length==0){help();return;}
        if(java.util.Set.of("--self-test","--demo","--server-sim","--hardware","--hardware-teleop").contains(args[0])) System.setProperty("java.awt.headless","true");
        switch(args[0]) {
            case "--new-key" -> System.out.println(java.util.HexFormat.of().formatHex(ControlProtocol.challenge()));
            case "--self-test" -> SelfTest.run(Path.of(args.length>1?args[1]:"test-report"));
            case "--demo" -> System.out.println(Demo.run(Path.of(args.length>1?args[1]:"demo-report"),args.length>2?Double.parseDouble(args[2]):90));
            case "--desktop", "--server-sim" -> {
                Simulator sim=new Simulator();RobotService robot=new RobotService(sim,sim,null);
                byte[] k=args[0].equals("--desktop")?ControlProtocol.challenge():key();
                int port=args[0].equals("--desktop")?0:Integer.parseInt(args[1]);
                ControlServer server=new ControlServer(robot,k,InetAddress.getByName(args[0].equals("--desktop")?"127.0.0.1":"0.0.0.0"),port);
                ScheduledExecutorService plant=Executors.newSingleThreadScheduledExecutor();
                plant.scheduleAtFixedRate(()->sim.advance(System.nanoTime()),0,20,TimeUnit.MILLISECONDS);
                Runtime.getRuntime().addShutdownHook(new Thread(()->{try{server.close();}catch(Exception ignored){}robot.close();plant.shutdownNow();}));
                robot.start();server.start();System.out.println("SIM_ORACLE_NOT_ML port="+server.port());
                if(args[0].equals("--desktop"))SwingUtilities.invokeLater(()->{
                    DesktopController ui=new DesktopController("127.0.0.1",server.port(),k,sim);ui.setVisible(true);
                    ui.addWindowListener(new java.awt.event.WindowAdapter(){@Override public void windowClosed(java.awt.event.WindowEvent e){System.exit(0);}});
                });else waitForever();
            }
            case "--controller" -> SwingUtilities.invokeLater(()->new DesktopController(args[1],Integer.parseInt(args[2]),key(),null).setVisible(true));
            case "--gamepad" -> {
                try(LinuxJoystick joy=new LinuxJoystick(Path.of(args[3]));ControlClient client=new ControlClient(args[1],Integer.parseInt(args[2]),key(),joy::command)) {
                    client.start();while(joy.connected()){Thread.sleep(1000);System.out.println(client.status);}
                }
            }
            case "--hardware-teleop" -> {
                Hardware hw=(Hardware)Class.forName("com.ubor.pi.PiHardware").getConstructor(Path.class).newInstance(Path.of(args[1]));
                try {
                    Perception camera=(Perception)Class.forName("com.ubor.ml.UvcCameraPerception").getConstructor(Path.class).newInstance(Path.of(args[1]));
                    RobotService robot=new RobotService(hw,camera,Path.of(args[3]));
                    ControlServer server=new ControlServer(robot,key(),InetAddress.getByName("0.0.0.0"),Integer.parseInt(args[2]));
                    Runtime.getRuntime().addShutdownHook(new Thread(()->{try{server.close();}catch(Exception ignored){}robot.close();}));
                    robot.start();server.start();waitForever();
                } catch(Exception|LinkageError e){hw.close();throw e;}
            }
            case "--hardware" -> {
                // Reflection keeps the executable simulator dependency-free. Real adapters are in Maven's full profile.
                Hardware hw=(Hardware)Class.forName("com.ubor.pi.PiHardware").getConstructor(Path.class).newInstance(Path.of(args[1]));
                Perception camera=null;RobotService robot=null;ControlServer server=null;
                try {
                    camera=(Perception)Class.forName("com.ubor.ml.UvcDl4jPerception").getConstructor(Path.class,Path.class).newInstance(Path.of(args[1]),Path.of(args[2]));
                    robot=new RobotService(hw,camera,args.length>4?Path.of(args[4]):null);
                    server=new ControlServer(robot,key(),InetAddress.getByName("0.0.0.0"),Integer.parseInt(args[3]));
                    final RobotService r=robot;final ControlServer s=server;
                    Runtime.getRuntime().addShutdownHook(new Thread(()->{try{s.close();}catch(Exception ignored){}r.close();}));
                    robot.start();server.start();waitForever();
                } finally {if(server!=null)server.close();if(robot!=null)robot.close();else{hw.close();if(camera!=null)camera.close();}}
            }
            default -> help();
        }
    }
    private static void help(){System.out.println("""
UBOR-JAVA R02 LEGACY_FIRST_ORDER -- Java 21 (not WPILib)
  --new-key                              generate a random shared secret
  --desktop                              Swing controller + 2D SIM_ORACLE
  --demo [output-dir] [seconds]           deterministic integration, NOT ML
  --self-test [output-dir]                offline assertion suite
  --server-sim PORT                       network simulator, UBOR_KEY required
  --controller HOST PORT                 keyboard remote controller
  --gamepad HOST PORT /dev/input/js0       Linux USB gamepad, UBOR_KEY required
  --hardware-teleop robot.properties PORT record-dir
  --hardware robot.properties models PORT [record-dir]
Hardware requires the Maven full classpath, calibrated hardware and approved models.
Space=hold deadman; W/S/A/D=drive; use on-screen ARM. Releasing focus disarms.
""");}
}

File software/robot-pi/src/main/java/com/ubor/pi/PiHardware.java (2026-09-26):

package com.ubor.pi;

import com.ubor.core.*;
import static com.ubor.core.Types.*;
import com.pi4j.Pi4J;
import com.pi4j.context.Context;
import com.pi4j.io.gpio.digital.*;
import com.pi4j.io.spi.*;
import com.pi4j.io.i2c.*;
import java.io.*;
import java.nio.file.*;
import java.util.*;

/** Pi4J 3.0.4 transport. Requires actual LinuxFS/GpioD providers and a commissioned board. */
public final class PiHardware implements Hardware {
    private final Context context;
    private final DigitalOutput arm,heartbeat;
    private final Map<Integer,DigitalInput> inputs=new HashMap<>();
    private final RegisterDevices.Mcp3008 adc;
    private final RegisterDevices.Ls7366r left,right;
    private final RegisterDevices.FourMotors motors;
    private final RangeCalibration range;
    private final int rightMotorSign,rightEncoderSign,leftMotorSign,leftEncoderSign;
    private boolean beat;
    public PiHardware(Path file)throws Exception {
        Properties p=new Properties();try(InputStream in=Files.newInputStream(file)){p.load(in);}
        if(!Boolean.parseBoolean(p.getProperty("calibration.complete","false")))throw new IllegalStateException("Hardware locked: complete commissioning, then approve calibration");
        Path base=file.toAbsolutePath().getParent();range=new RangeCalibration(base.resolve(p.getProperty("range.calibration","range-calibration.csv")));
        leftMotorSign=sign(p,"motor.left.sign");rightMotorSign=sign(p,"motor.right.sign");leftEncoderSign=sign(p,"encoder.left.sign");rightEncoderSign=sign(p,"encoder.right.sign");
        if(Integer.parseInt(p.getProperty("encoder.counts.per.wheel.rev","0"))!=2048)throw new IllegalStateException("Update DriveControl calibration or provide 2048 actual counts per wheel revolution");
        context=Pi4J.newAutoContext();
        DigitalOutput a=null;
        try {
            arm=output("software-arm",27);a=arm;arm.low();
            heartbeat=output("deadline-heartbeat",22);heartbeat.low();
            for(int pin:new int[]{23,24,25,5,6,12,13,16,26})inputs.put(pin,context.create(DigitalInput.newConfigBuilder(context).id("input-"+pin).address(pin).pull(PullResistance.PULL_UP).provider("gpiod-digital-input").build()));
            adc=new RegisterDevices.Mcp3008(bus("adc",0,0,500_000));
            RegisterDevices.Mcp23s17 directions=new RegisterDevices.Mcp23s17(bus("direction",0,1,500_000));
            left=new RegisterDevices.Ls7366r(bus("encoder-left",1,0,500_000));right=new RegisterDevices.Ls7366r(bus("encoder-right",1,1,500_000));
            I2C device=context.create(I2C.newConfigBuilder(context).id("motor-pwm").bus(1).device(0x40).provider("linuxfs-i2c").build());
            RegisterDevices.Pca9685 pwm=new RegisterDevices.Pca9685(tx->{try{if(device.write(tx)<0)throw new IOException("I2C write failed");}catch(RuntimeException e){throw new IOException(e);}});
            pwm.init();directions.init();left.init();right.init();motors=new RegisterDevices.FourMotors(directions,pwm);motors.set(Actuation.off());
        } catch(Exception|LinkageError e) {if(a!=null)a.low();context.shutdown();throw e;}
    }
    private static int sign(Properties p,String key) {int v=Integer.parseInt(p.getProperty(key,"0"));if(v!=1&&v!=-1)throw new IllegalArgumentException("Calibrate "+key+" to +1/-1");return v;}
    private DigitalOutput output(String id,int pin) {return context.create(DigitalOutput.newConfigBuilder(context).id(id).address(pin).initial(DigitalState.LOW).shutdown(DigitalState.LOW).provider("gpiod-digital-output").build());}
    private RegisterDevices.SpiBus bus(String id,int bus,int chipSelect,int baud) {
        Spi spi=context.create(Spi.newConfigBuilder(context).id(id).bus(bus).address(chipSelect).baud(baud).mode(SpiMode.MODE_0).provider("linuxfs-spi").build());
        return tx->{try{byte[] rx=new byte[tx.length];int status=spi.transfer(tx,rx);if(status<0)throw new IOException("SPI failure "+id);return rx;}catch(RuntimeException e){throw new IOException(e);}};
    }
    private boolean high(int pin){return inputs.get(pin).isHigh();}
    private double current(int channel)throws IOException {return adc.volts(channel)/.6825;}
    @Override public synchronized Sensors read(long now)throws Exception {
        double battery=adc.volts(0)*11;
        double l=current(1),r=current(2),brush=current(3),belt=current(4);
        double front=range.meters(adc.volts(5));
        // Timestamp is the START of the scan. The supervisor evaluates age AFTER read() completes.
        return new Sensors(now,battery,front,high(23),high(24),high(25),high(5),high(6),!high(26),!high(16),!high(12),!high(13),
                l,r,brush,belt,left.count()*leftEncoderSign,right.count()*rightEncoderSign);
    }
    @Override public synchronized void apply(Actuation command,long now)throws Exception {
        if(!command.enabled())arm.low();
        Actuation signed=new Actuation(command.enabled(),command.left()*leftMotorSign,command.right()*rightMotorSign,command.brush(),command.belt());
        motors.set(signed);
        if(command.enabled())arm.high();
        // The TPS3431 requires falling edges: toggling every completed 20 ms cycle gives one per 40 ms.
        // NEVER move this to a timer independent from successful I/O completion.
        beat=!beat;if(beat)heartbeat.high();else heartbeat.low();
    }
    @Override public synchronized void close()throws Exception {
        arm.low();try{motors.set(Actuation.off());}finally{heartbeat.low();context.shutdown();}
    }
}

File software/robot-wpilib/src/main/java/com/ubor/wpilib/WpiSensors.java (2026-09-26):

package com.ubor.wpilib;

import com.ubor.app.SimDynamics;
import com.ubor.core.DriveControl;
import static com.ubor.core.Types.*;
import edu.wpi.first.wpilibj.*;
import edu.wpi.first.wpilibj.simulation.*;

/** Virtual channels only, NOT Raspberry Pi BCM pin numbers and NOT SPI chip emulation. */
final class WpiSensors implements AutoCloseable {
    private final Encoder left=new Encoder(0,1),right=new Encoder(2,3);
    private final EncoderSim leftSim=new EncoderSim(left),rightSim=new EncoderSim(right);
    private final AnalogGyro gyro=new AnalogGyro(0,0,0.0); // preset center, no blocking calibration
    private final AnalogGyroSim gyroSim=new AnalogGyroSim(gyro);
    // AI1 range: 1 V/m. AI2..5 current: 0.5 V/A. Saturation is explicitly modelled.
    private final AnalogInput range=new AnalogInput(1);
    private final AnalogInputSim rangeSim=new AnalogInputSim(range);
    private final AnalogInput[] current=new AnalogInput[4];
    private final AnalogInputSim[] currentSim=new AnalogInputSim[4];
    // DIO4..12: NC estop/bumper/cliff/cover, full, permit, driver fault, intake, drop.
    private final DigitalInput[] digital=new DigitalInput[9];
    private final DIOSim[] digitalSim=new DIOSim[9];
    private boolean closed;
    WpiSensors(){
        double perPulse=2*Math.PI*DriveControl.WHEEL_R_M/DriveControl.COUNTS_PER_TURN;
        left.setDistancePerPulse(perPulse);right.setDistancePerPulse(perPulse);
        for(int i=0;i<4;i++){current[i]=new AnalogInput(i+2);currentSim[i]=new AnalogInputSim(current[i]);}
        for(int i=0;i<9;i++){digital[i]=new DigitalInput(i+4);digitalSim[i]=new DIOSim(digital[i]);}
    }
    void updateMotion(SimDynamics.State s){
        leftSim.setDistance(s.leftPosition());rightSim.setDistance(s.rightPosition());
        leftSim.setRate(s.leftVelocity());rightSim.setRate(s.rightVelocity());
        // WPILib physics is CCW positive; AnalogGyro angle is CW positive.
        gyroSim.setAngle(-Math.toDegrees(s.heading()));
        gyroSim.setRate(-Math.toDegrees((s.rightVelocity()-s.leftVelocity())/DriveControl.TRACK_M));
        RoboRioSim.setVInVoltage(s.batteryV()); // 25.6 V model bus, not default 12 V FRC battery
        double[] amps={s.leftCurrent(),s.rightCurrent(),s.brushCurrent(),s.beltCurrent()};
        for(int i=0;i<4;i++)currentSim[i].setVoltage(clamp(amps[i]*.5,0,5));
    }
    Sensors roundTrip(long now,Sensors s){
        rangeSim.setVoltage(clamp(s.frontRangeM(),0,5));
        boolean[] levels={!s.emergency(),!s.bumper(),!s.cliff(),!s.coverOpen(),s.hopperFull(),
            s.hardwarePermit(),s.driverFault(),s.intakeBeam(),s.dropBeam()};
        for(int i=0;i<9;i++)digitalSim[i].setValue(levels[i]);
        return new Sensors(now,RobotController.getBatteryVoltage(),range.getVoltage(),
            !digital[0].get(),!digital[1].get(),!digital[2].get(),!digital[3].get(),digital[4].get(),digital[5].get(),
            digital[6].get(),digital[7].get(),digital[8].get(),
            current[0].getVoltage()*2,current[1].getVoltage()*2,current[2].getVoltage()*2,current[3].getVoltage()*2,
            left.get(),right.get());
    }
    double headingRadians(){return gyro.getRotation2d().getRadians();}
    double leftDistance(){return left.getDistance();}
    double rightDistance(){return right.getDistance();}
    @Override public void close(){
        if(closed)return;closed=true;
        for(DigitalInput d:digital)if(d!=null)d.close();
        for(AnalogInput a:current)if(a!=null)a.close();
        range.close();gyro.close();right.close();left.close();
    }
}
